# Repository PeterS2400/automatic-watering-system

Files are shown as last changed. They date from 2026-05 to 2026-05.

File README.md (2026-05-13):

# Automatic Plant Watering System

An automatic watering system for 8 potted plants. A single 12V solenoid valve releases water from a gravity-fed reservoir into a drip manifold. Each plant has its own Luer-slip syringe intermediate reservoir sized to hold exactly that plant's target water dose. When the valve opens all reservoirs fill simultaneously; when it closes, water drips slowly from each reservoir to its plant over 1–3 minutes. A Seeed Tiny BLE (nRF51822) controls the valve on a fixed 24-hour interval.

Per-plant water volume is controlled **physically** by syringe plunger position, not by software. The firmware only opens and closes the valve.

**Status:** Electronics assembled and firmware running. Valve cycle confirmed. Power path via barrel jack still being resolved. Enclosure CAD started.

---

## How it works

```
Gravity reservoir (2.5-gal HDPE bucket, ~1m above plants)
  [copper mesh basket inside, over bulkhead inlet]
  → 1/2" bulkhead → 1/2" ID silicone supply line
  → 12V solenoid valve (normally closed)
  → 1/2" ID silicone feed line
  → Orbit 67000 8-port drip manifold
  → 8× 1/4" ID fill lines → Luer-slip syringe intermediate reservoirs
  → 8× 1/8" ID silicone drip lines → plants
```

```
120V AC → Meanwell 12V/5A PSU → 12V rail
  → solenoid valve (via TIP121G NPN Darlington transistor switch)
  → LM2596 buck converter → 5V → Seeed Tiny BLE (USB injection)
```

---

## Architecture

Two approaches were evaluated before committing to hardware.

| | Option A — single valve (chosen) | Option B — per-plant valves |
|---|---|---|
| Valves | 1 | 8 |
| Electronics complexity | Low | Medium |
| Adjusting per-plant amounts | Slide syringe plunger | Change a config value |
| Plumbing complexity | Medium (intermediate reservoirs) | Low (direct drip lines) |

**Why Option A:** fewer failure points, simpler electronics, and volume adjustment doesn't require reflashing firmware. The intermediate reservoir approach is visible and debuggable — you can watch each reservoir fill and drain.

---

## Hardware

### Microcontroller

**Seeed Tiny BLE (nRF51822)** — ARM Cortex-M0, 16MHz, 3.3V logic.

- Timing: `millis()`-based 24-hour interval; no WiFi, no NTP, no RTC
- Drift: ~2–4s/day — acceptable for daily plant watering
- Programmed via CMSIS-DAP drag-and-drop: Sketch → Export Compiled Binary in Arduino IDE, drag `.hex` to the MBED drive in Finder. Board package: sandeepmistry nRF5, Generic nRF51.
- GPIO P4 drives the valve; nRF51822 requires H0H1 high-drive mode via direct NRF_GPIO register write (firmware handles this)
- LED pins (confirmed on hardware): GREEN = 21, RED = 22, BLUE = 23. Active LOW.

### Transistor driver

**TIP121G NPN Darlington** (TO-220), 470Ω base resistor, **10kΩ base pull-down to GND**, 1N4007 flyback diode.

- TIP121G is a Darlington with h_FE ≥ 1000 — nRF51822 H0H1 GPIO sources ~5mA, which saturates the TIP121G at 5A; the 500mA solenoid is trivial. The original ZTX650 was replaced because its h_FE of ~50–80 at 500mA was insufficient for saturation with 5mA base drive, causing it to operate in the linear region and overheat.
- Pinout (TO-220, leads facing you): B – C – E left to right; metal tab = collector
- 470Ω limits base current and accounts for the Darlington's two V_BE drops (~1.4V total): I_B = (3.3 − 1.4) / 470 ≈ 4mA
- **10kΩ pull-down** holds the base at 0V when the GPIO is inactive — a floating base picks up noise, partially enables the transistor, and generates destructive inductive spikes (this destroyed the first ZTX650 on initial power-up with the MCU disconnected)
- 1N4007 flyback diode clamps the inductive spike when the valve closes (cathode to 12V rail)
- No heatsink required — V_CE(sat) ≈ 1V at 500mA gives ~500mW dissipation, well within TO-220 limits

### Power

**Meanwell GST60A12** — 12V/5A desktop brick, UL/CE certified, continuous duty.

- 12V feeds solenoid coil (~500mA peak) and LM2596 input
- LM2596 buck converter steps down to 5V for Tiny BLE via USB injection; module uses screw terminals — Meanwell barrel jack connects via pigtail, no adapter needed

### Solenoid valve

12V DC, normally closed, 1/2" NPT, VITON seal (U.S. Solid brass body).

- **Direct-acting** — opens at zero pressure; works with gravity feed at any head height (pilot-operated valves require ~0.3 bar minimum pressure — avoid those)
- 1/2" NPT chosen over 1/4": the 1/2" valve has a ~10–12mm orifice so tubing, not the valve, is the flow bottleneck

### Intermediate reservoirs

All 8 plants use Luer-slip syringes with the plunger as an adjustable volume limiter.

- Fill tube (1/4" ID) drilled through center of plunger disc — interference fit + silicone sealant
- Plunger locked at desired volume mark with a cable tie through the barrel ears
- Drip line (1/8" ID) push-fits onto Luer nozzle — no barb fitting needed
- Volume adjustment: loosen cable tie, slide plunger to new mark, re-tighten

### Tubing

| Use | Spec |
|---|---|
| Supply runs (bulkhead → valve, valve → manifold) | 1/2" ID × 3/4" OD silicone, 10 ft |
| Fill lines (manifold → reservoirs) | 1/4" ID × 1/2" OD silicone, 25 ft |
| Drip lines (reservoirs → plants) | 1/8" ID × 1/4" OD silicone, 50 ft |

### Enclosure

3D-printed, two-part: body + lid. Lid secured with screws. Single parting line shared between the lid joint and both cable glands.

- **Power entry:** IEC C8 panel-mount socket; 12V DC pigtail from Meanwell barrel jack inside
- **Solenoid cable entry:** 2-wire, 12V switched; detachable connector inside (DIN 43650A preferred)
- **USB access:** remove lid — no panel port

Cable glands are fully integrated into the print. The body/lid split is the gland split — screwing the lid down clamps the cable. No purchased glands or separate clamp parts.

- Power cable bore: 5.9mm (cable OD 6.35mm)
- Solenoid cable bore: 2.8mm (cable OD 3.175mm)

Interior dimensions: 65mm × 85mm floor, 45mm height to parting line.

Boards mount via L-shaped corner extrusions from the walls. Bottom 2 corners are full L-shape (supports weight); top 2 corners are side tabs only (allows straight insertion from above, no overhangs to print). Boards sit slightly lower than their natural wire resting point so wire tension presses them into the supports.

---

## Firmware

**`firmware_ble/`** — Arduino C++ targeting Seeed Tiny BLE (nRF51822). Currently set to alternating open/closed cycle for calibration.

Key firmware constants (edit in `firmware_ble/watering_system/watering_system.ino`):

```cpp
#define VALVE_PIN    4   // GPIO pin to transistor base
#define VALVE_ON_S  20   // seconds valve stays open each cycle
#define VALVE_OFF_S 20   // seconds valve stays closed each cycle
```

LED: blue while valve is open, green while closed. 3 green blinks on boot.

---

## Bill of materials

### Electronics

| Item | Cost | Notes |
|---|---|---|
| Seeed Tiny BLE (nRF51822) | $0 (owned) | Microcontroller |
| 12V DC solenoid valve, NC, 1/2" NPT, VITON | $35 | U.S. Solid brass, direct-acting |
| TIP121G NPN Darlington transistor (TO-220) | $0 (stash) | Valve driver |
| 470Ω resistor (1/4W) | $0 (stash) | Base resistor |
| 10kΩ resistor (1/4W) | $0 (stash) | Base pull-down to GND |
| 1N4007 diode | $0 (stash) | Flyback protection |
| Meanwell GST60A12 12V/5A PSU | $0 (reused) | Continuous duty, UL/CE |
| LM2596 buck converter module (5-pack) | $9 | 12V→5V; screw terminal inputs |
| IEC C8 panel-mount socket | $0 (stash) | Power entry on enclosure |
| Perfboard, jumper wire, screw terminals | $0 (stash) | Driver circuit board |

### Plumbing

| Item | Cost | Notes |
|---|---|---|
| HDPE 2.5-gal black bucket + Gamma-seal lid | $18 | Food-grade, opaque |
| 1/2" NPT bulkhead fitting + EPDM gasket | — | Reservoir outlet (included in fittings total) |
| Copper mesh, 100–200 mesh, food-safe | $13 | Basket inside bucket over inlet |
| 1/2" NPT-F × 1/2" barb adapter, brass (×1) | — | Bulkhead → supply tube (included in fittings total) |
| 1/2" NPT-M × 1/2" barb adapter, brass (×3) | — | Valve inlet, valve outlet, manifold inlet (included in fittings total) |
| Bulkhead + barb adapters ×4 + PTFE tape | $25 | All fittings combined |
| Orbit 67000 8-port drip manifold | $18 | 1/2" FPT inlet, 1/4" barb outlets (bought 2-pack, 1 spare) |
| Silicone tubing 1/2" ID × 3/4" OD, 10 ft | — | Main supply runs (included in tubing total) |
| Silicone tubing 1/4" ID × 1/2" OD, 25 ft | — | Fill lines (included in tubing total) |
| Silicone tubing 1/8" ID × 1/4" OD, 50 ft | — | Drip lines (included in tubing total) |
| Silicone tubing (all 3 spools) | $35 | |

### Intermediate reservoirs

| Item | Cost | Notes |
|---|---|---|
| 150ml Luer-slip syringes (×6) | $23 | All plants; no small syringes needed |
| Cable zip ties (600pc) | $13 | Lock syringe plungers |
| Aquarium-grade silicone sealant | — | Included in sealant + pegboard total |
| Pegboard (syringe mounting, replaces rack) | — | Included in sealant + pegboard total |
| Silicone sealant + pegboard | $35 | |

### Enclosure

| Item | Cost | Notes |
|---|---|---|
| 3D-printed body + lid | $2 | Filament only; own printer |

### Cost summary

| Category | Cost |
|---|---|
| Electronics | $44 |
| Plumbing | $109 |
| Intermediate reservoirs | $71 |
| Enclosure | $2 |
| **Total** | **~$226** |

---

## Open items

- Resolve barrel-jack power path: LM2596 currently outputs 5V but Tiny BLE VCC pin expects 3.7–4.2V (LiPo range); either trim LM2596 to 4V or route 5V via USB injection permanently
- Update firmware from calibration cycle (20s on/off) to production schedule (24h interval) once fill duration is confirmed
- Determine per-plant water volumes → select small syringe sizes and quantities
- Calibrate valve open duration: increase VALVE_ON_S until all intermediate reservoirs fill without overflow
- Measure LM2596 module dimensions → model corner extrusions in CAD
- Finalize solenoid-side detachable connector (DIN 43650A preferred)
- Complete enclosure CAD and print
- Full system test

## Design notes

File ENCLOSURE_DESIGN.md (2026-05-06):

# Enclosure Design Notes

3D-printed enclosure, two-part: main body + lid. Lid secured with screws. Single parting line shared by lid joint and cable glands.

---

## External Interfaces

All penetrations through the enclosure wall.

### 1. Power Entry — 12V DC from Meanwell PSU

| Property | Detail |
|---|---|
| Signal | 12V DC, up to 5A |
| External connector | IEC 60320 C8 panel-mount socket (already decided) |
| Cable from Meanwell | Barrel jack (5.5×2.5mm, center+) → pigtail → C8 plug |
| Strain relief | Split cable gland, 3D-printed into enclosure body |
| Water resistance | Split gland geometry seals around cable jacket |
| Inside termination | Pigtail wires to perfboard screw terminals (12V+, GND) |

### 2. Solenoid Cable Entry — 12V switched + GND

| Property | Detail |
|---|---|
| Signal | 12V DC, ~500mA switched; 2-wire |
| Strain relief | Split cable gland, 3D-printed into enclosure body |
| Water resistance | Split gland geometry seals around cable jacket |
| Detachable connector | TBD — options discussed: DIN 43650A, GX12/GX16, XT30, pluggable screw terminal |
| Connector location | Inside the enclosure wall — cable gland on outside, connector socket on inside |
| Outside cable | Solenoid power cable, already attached to valve, terminates in mating connector plug |

### 3. USB Access — Tiny BLE programming

No panel interface. Remove lid to access USB port.

---

## Internal Components

| Component | Orientation | Mounting method |
|---|---|---|
| Seeed Tiny BLE (nRF51822) | Sideways (standing on edge) | 4 L-shaped corner extrusions from wall; lid presses top edge down to lock |
| LM2596 buck converter module | Sideways (standing on edge) | 4 L-shaped corner extrusions from wall; lid presses top edge down to lock |
| Perfboard | Flat | Standoffs from floor + M3 screws; drill holes in perfboard to match |

**Corner extrusion detail:**
- **Bottom 2 corners:** Full L-shape — captures the side and bottom edge of the board. Supports the board's weight and prevents forward/downward movement.
- **Top 2 corners:** Side tab only — grips the sides of the board but has no lip over the top edge. Prevents lateral movement without obstructing insertion from above. Avoids overhangs in the print.
- Lid closes over the top edge to provide the only top retention.
- Board drops straight in from above and lifts straight out — no angling or squeezing required.

Board dimensions (measured):
- Perfboard: 40mm × 60mm
- Seeed Tiny BLE: 38.5mm × 42mm
- LM2596 buck converter: TBD — measure before modeling

**Wire tension retention:** The Tiny BLE and LM2596 are positioned slightly lower than their natural resting point as determined by the connected wiring. The slight downward offset puts the wires in gentle tension/bend, which presses the boards down into their corner supports and prevents rattling without any additional fasteners.

Orient each board so tallest components face into available clearance.

---

## Dimensions

- Body interior height (floor to parting line): 45mm
- Body interior floor: 65mm × 85mm

## Lid

- Secured with screws (count and size TBD)
- Consider heat-set brass inserts in the body for cleaner screw attachment
- Lid removal provides USB access for firmware updates

---

## Split Cable Gland Design Notes

Both cable penetrations are fully integrated into the 3D-printed enclosure — no purchased glands, no separate clamp parts.

**Split geometry:**
- Single parting line: the body/lid split IS the gland split
- Lower half of each gland is part of the enclosure body; upper half is part of the lid
- Screwing the lid down clamps the cable — no additional hardware

**Bore and fit:**
- Power cable OD: 1/4" (6.35mm) → model bore at ~5.9mm
- Solenoid cable OD: 1/8" (3.175mm) → model bore at ~2.8mm
- Slight interference fit (~0.3–0.5mm under cable OD) so the lid clamps the jacket when tightened
- Interior shoulder or step inside the enclosure wall prevents the cable being pulled inward under tension

**Water resistance:**
- Exterior chamfer sheds water away from the opening
- Optionally apply a thin bead of silicone sealant inside the bore at final assembly for a positive seal

---

## Open Items

- Finalize solenoid-side detachable connector (DIN 43650A is the natural fit — same family as the connector on the valve coil itself)
- Decide USB access method (panel port vs. lid removal)
- ~~Measure actual cable ODs before modeling gland bores~~ **Resolved:** power 6.35mm, solenoid 3.175mm
- Determine screw size and count for lid
- Determine internal mounting strategy for perfboard and LM2596 module (standoffs, snap clips, or adhesive)

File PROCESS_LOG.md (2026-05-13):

# Process Log: Automatic Plant Watering System

---

## 2026-03-24 — Project initiation & BOM setup

### Decisions recorded

| Decision | Choice | Notes |
|---|---|---|
| Architecture | **Option A — single valve + intermediate reservoirs** | 1 solenoid valve; per-plant volume controlled by intermediate reservoir size |
| Plant count | **8 plants** | Upper end of planned range |
| Controller + driver | **ESP32 dev board + ZTX650 transistor circuit** | Single valve; same circuit as original CLAUDE.md design. 12V→5V buck converter for ESP32 power. |
| Intermediate reservoirs | **Hybrid: Luer-slip syringes (≤60ml) + PP lab bottles (>60ml)** | Syringes: plunger kept as adjustable fill ceiling; drill fill port through plunger disc; lock plunger with cable tie through barrel ears. Bottles: drill near base, rubber grommet + 1/8" barb; volume changed by swapping bottle size. |
| WiFi / remote control | **Yes — build it in now** | Schedule and status accessible remotely |
| Manifold | **Off-shelf 8-port drip manifold** | e.g. Orbit/Rain Bird; 1/4" barb outlets. Reducer couplers eliminated — fill lines are 1/4" ID silicone, direct fit on barb. |
| Enclosure | **3D-printed** | Custom design, no purchased project box |
| Power supply | **Meanwell GST60A12, 12V/5A desktop brick** | UL/CE certified, continuous duty; 5.5×2.5mm barrel jack |
| Fill line tubing | **Silicone, 1/4" ID × 1/2" OD, 25 ft spool** | Manifold → intermediate reservoir tops. Direct fit on 1/4" barb; fills 500ml in <10s at 1m head. |
| Drip line tubing | **Silicone, 1/8" ID × 1/4" OD, 50 ft spool** | Intermediate reservoir outlet → plant. Drains 200ml in ~1 min at 0.2m head. Target: 1–3 min delivery. |

---

### Tubing research — 2026-03-24

Compared four material options for the drip lines (gravity-fed, low-pressure, indoor).

**Materials evaluated:** silicone, vinyl/PVC, polyurethane (PU), PTFE

**Summary:**

| | Silicone | Vinyl (PVC) | PU | PTFE |
|---|---|---|---|---|
| Plant/food safe | Yes | Yes (food-grade only) | Yes (food-grade) | Yes |
| Flexibility | Excellent | Good | Good | Poor |
| Kink resistance | Moderate | Moderate | Good | Poor |
| Transparency | Clear grades available | Clear–hazy | Clear grades available | Milky/translucent |
| Barbed fitting fit | Excellent | Excellent | Good | Poor |
| Longevity | Excellent | Fair (hardens over years) | Good | Excellent |
| Cost | Moderate–high | Low | Moderate | Moderate–high |
| Indoor drip suitability | **Excellent** | Good | Good | Poor |

**Recommendation from research:** Silicone, 1/8" ID × 1/4" OD. Fully inert, stays flexible, fits barbed fittings without clamps, safe for plants long-term.

**Budget alternative (not selected):** Aquarium-grade vinyl airline tubing (3/16" ID) — adequate for indoor use, replace every 2–3 years.

**PTFE note:** Not suitable for flexible drip routing due to stiffness, but fine-bore PTFE capillary (~1/16" ID) could be used as a short in-line flow restrictor at the plant outlet if precise slow drip rates are needed.

**User selection:** Silicone (recommended option).

---

---

### Power supply research — 2026-03-24

Compared generic wall warts, reputable brand wall-mount, generic desktop bricks, and Meanwell branded bricks.

**Key findings:**
- System draws 8 × 500mA = 4A peak; ≥5A supply recommended for headroom
- Generic adapters: certification authenticity questionable; thermal performance at sustained 4A varies; not recommended for unattended 24/7 operation
- Meanwell: verified UL/CE, published MTBF (>100k hours), designed for continuous embedded deployment
- Barrel jack: generic adapters use 5.5×2.1mm; Meanwell typically uses 5.5×2.5mm — a $1 adapter resolves any mismatch
- Solenoids are inductive loads; switching PSUs handle them fine; flyback diodes already in BOM are the correct mitigation

**User selection:** Meanwell GST60A12 (12V/5A desktop brick).

---

### Reservoir research — 2026-03-24

Compared HDPE buckets, collapsible bladders, beverage dispensers, garden reservoirs, and jerrycans.

**Key findings:**
- Collapsible bladders: head pressure drops as they collapse — incompatible with gravity-fed flow
- Most beverage dispensers are clear/translucent — algae risk; opaque options hard to source reliably
- Jerrycans: excellent in all respects except no viable bottom outlet (shape prevents bulkhead fitting)
- HDPE bucket: opaque (black), food-grade, H₂O₂-compatible, easy bulkhead fitting, cheap, standard Gamma-seal lid available
- 2.5-gallon (9.5L) keeps full weight under 10kg on shelf; covers 2–3 watering cycles before refill

**User selection:** Black food-grade HDPE 2.5-gal bucket + Gamma-seal lid + 1/2" NPT bulkhead fitting + EPDM gasket.

---

### Fittings & manifold research — 2026-03-24

**Critical barb sizing clarification:** Barb OD matches tubing ID. 1/8" barb → 1/8" ID tubing. Standard drip manifolds use 1/4" barb outlets (sized for 1/4" ID poly tubing, not 1/8" ID silicone) — requires reducers.

**Manifold options evaluated:**
- Off-shelf (Orbit/Rain Bird 8-port): ~$10–20; outlets are 1/4" barb — needs 8× 1/4"→1/8" reducer couplers (~$4–16). Total ~$15–35.
- 3D-printed PETG with native 1/8" barbs: ~$7–12 in materials, no reducers, but requires design/print time. FDM is not inherently waterproof; PETG + CA glue coat seals adequately at gravity pressure.

**User selection:** Off-shelf manifold + 8× 1/4"→1/8" reducer couplers.

**Complete fitting chain:**
```
Reservoir bulkhead (1/2" NPT) → strainer → manifold (3/4" FHT or 1/2" NPT inlet)
→ manifold 1/4" barb outlets → 1/4"→1/8" reducer couplers × 8
→ 1/4" NPT close nipples × 8 → valve inlets (1/4" NPT-F)
→ valve outlets (1/4" NPT-F) → 1/4" NPT-M × 1/8" barb adapters × 8
→ 1/8" ID silicone drip lines × 8 → plants
```

**Sealing:** PTFE tape on all NPT threads; no hose clamps on silicone at gravity pressure.

---

### Valve driver research — 2026-03-24 (superseded by Option A switch)

Originally researched for Option B (8 valves). Superseded when architecture switched to Option A (1 valve). Full comparison retained in PROJECT_PLAN.md §1.6 for reference.

**Summary of what was found (for record):** ULN2803A (2 ICs, 4 channels each) was the lowest-cost DIY option; Waveshare ESP32-S3-ETH-8DI-8RO was the best all-in-one. Key ESP32 gotcha: 3.3V GPIO — most cheap relay modules require 5V and won't trigger reliably.

**Outcome:** Architecture switched to Option A (1 valve). Driver circuit reduced to single ZTX650 NPN transistor + 470Ω base resistor + 1N4007 flyback diode — the original CLAUDE.md design.

---

### Tubing flow rate research — 2026-03-24

Researched fill line and drip line sizing separately after deciding on two-tube approach.

**Fill lines (manifold → intermediate reservoirs):**
- Turbulent flow regime at relevant head heights — Darcy-Weisbach used
- 1/4" ID at 1m head fills 500ml in ~8s, 200ml in ~3s — essentially instantaneous
- 1/4" ID silicone fits directly on standard 1/4" barb manifold outlets → no reducer couplers needed
- **Selected: 1/4" ID × 1/2" OD silicone, 25 ft spool**

**Drip lines (intermediate reservoir → plant):**
- Laminar flow regime at ~0.2m head from small reservoirs
- 1/8" ID at 0.2m head, 1m run: ~200ml drains in ~40–60s; 50ml in ~10–15s
- PTFE capillary (0.8mm ID) evaluated — provides hours-long drip but rejected by user (target: 1–3 minute delivery)
- Length tuning viable for fine adjustment within ~2× range
- **Selected: 1/8" ID × 1/4" OD silicone, 50 ft spool**

---

### Intermediate reservoir research — 2026-03-24

Researched commercial products (syringes, IV bags, drip stakes) and DIY containers (bottles, Falcon tubes, 3D-printed, glass).

**Key findings:**
- Drip stakes and IV bags: not suitable (pressurized design / sealed fill problem)
- Falcon/centrifuge tubes: elegant conical drain, rack mounting included, but 50ml hard limit
- 3D-printed PETG: cleanest result with integrated barbs; needs design work and CA glue coat for waterproofing
- Oral syringes (Luer-slip, plunger removed): zero modification, 1/8" silicone push-fits directly onto Luer nozzle, 10–60ml range
- PP lab reagent bottles (wide-mouth): drill near base, rubber grommet + 1/8" barb, 125–500ml range. Do NOT use hot glue (fails on PP). Silicone sealant alone won't bond PP without primer — rubber grommet is primary seal.

**User selection:** Hybrid — syringes for small plants (≤60ml), PP lab bottles for large plants (>60ml).

- [x] Architecture switched to **Option A** — 1 valve, intermediate reservoirs. Electronics simplified to ESP32 + single ZTX650 circuit.
- [x] Intermediate reservoir type selected: **syringes (≤60ml) + PP lab bottles (>60ml)**
- [x] Syringe volume control: **plunger-as-limiter** — drill fill port through plunger disc, lock plunger position with cable tie through barrel ears. Continuously adjustable, readable from barrel graduation markings.
- [x] Tubing: two sizes — 1/4" ID fill lines (fast), 1/8" ID drip lines (1–3 min delivery)
- [x] Reducer couplers eliminated — 1/4" ID fill lines fit directly on manifold 1/4" barb outlets
- [ ] Determine per-plant water volumes → confirm syringe/bottle sizes and quantities needed

---

### Open items as of 2026-03-24

- [x] Silicone tubing: **1/4" ID × 1/2" OD, 25 ft** (fill lines) + **1/8" ID × 1/4" OD, 50 ft** (drip lines)
- [x] Reducer couplers eliminated — fill lines are 1/4" ID, direct fit on manifold barbs
- [ ] Determine per-plant water volumes → finalize syringe/bottle sizes and quantities
- [ ] Barrel jack adapter (5.5×2.5mm → 5.5×2.1mm) — confirm during electronics design
- [ ] Manifold specific product — confirm outlet type (1/4" NPT-F vs. 1/4" barb) before ordering fittings

---

## 2026-03-24 — Manifold selection, BOM refinements, electrical interface documentation

### Intermediate reservoir quantities confirmed

Minimum quantities set: **at least 4 syringes** (≤60ml plants) + **at least 4 bottles** (>60ml plants). Final sizes still TBD per plant. BOM updated from TBD to 4+.

---

### Manifold research — 2026-03-24

Researched 6 manifold types: off-shelf drip irrigation, aquarium/hydroponics, DIY barbed tee chain, DIY 1/2" header with punch-ins, drilled PVC pipe, 3D-printed PETG. Full detail in `manifold_options.md`.

**Key findings:**

| Finding | Result |
|---|---|
| Off-shelf 8-port manifold outlet type | **1/4" barb universally** (Orbit, Raindrip, Rain Bird, DIG) — not NPT-F. Direct fit for 1/4" ID silicone fill lines. |
| Off-shelf manifold inlet type | **1/2" FPT** on all models — needs one adapter to connect to 1/4" ID supply line |
| Gravity-feed compatibility | Non-pressure-compensating manifolds pass gravity flow freely with knobs open. Pressure-compensating emitter inserts block flow at gravity pressure — do not install. |
| Aquarium manifolds | Outlet barbs are 3/16" or ~5.5mm — too small for 1/4" ID fill lines. Not compatible. |

**User selection:** **Orbit 67000** (~$8) + **Rain Bird XT025** inlet adapter (1/4" barb × 1/2" FPT female, ~$1–2).

**Resolved open item:** Manifold outlet type confirmed as 1/4" barb. No NPT-F adapters needed at outlet side.

---

### LM2596 datasheet review — 2026-03-24

Reviewed Addicore AD281 LM2596 datasheet. Document is the National Semiconductor LM2596 IC datasheet — covers the 5-pin TO-220/TO-263 chip only. No barrel jack is present on the IC itself.

**Finding:** The LM2596 module board (Addicore AD281 and equivalent cheap modules) uses **screw terminals** for 12V input and 5V output — no barrel jack socket. The Meanwell PSU's 5.5×2.5mm barrel jack therefore does not plug into a module socket; instead the 12V is distributed via a pigtail wire from the barrel jack to screw terminals on the perfboard.

**Resolved open item:** Barrel jack adapter (5.5×2.5mm → 5.5×2.1mm) — **not applicable**. No adapter needed.

---

### Inline strainer replaced with copper mesh basket — 2026-04-22

**Decision:** Remove inline sediment strainer; use copper mesh basket inside the bucket instead.

**Rationale:** A copper mesh basket (100–200 mesh) formed over the bulkhead inlet opening inside the bucket does the same filtration job as an inline strainer while also providing the antimicrobial Cu²⁺ release already planned for water quality. Consolidates two separate items into one, removes a plumbing fitting from the line, and simplifies the supply chain.

**Changes made:**
- Inline strainer row removed from BOM
- Copper mesh sheet/roll added to BOM (replaces both strainer and previously separate copper insert)
- Fitting chain updated: bulkhead → valve directly (strainer hop removed)
- Section 1.3 water quality note updated to describe dual-purpose copper mesh basket

---

### Bucket-to-valve tube segment added — 2026-04-22

**Issue:** Removing the inline strainer left the fitting chain with no tubing or adapters specified between the bulkhead and the valve inlet. That segment was silently missing from the BOM.

**Changes made:**
- Added 1/2" NPT-F × 1/2" barb adapter (×1) — female NPT threads onto bulkhead's external male NPT thread; barb accepts supply tube
- 1/2" NPT-M × 1/2" barb adapter qty increased from 2 to 3 (valve inlet added to existing valve outlet + manifold inlet uses)
- 1/2" ID silicone spool bumped from 5 ft to 10 ft to cover both runs (bulkhead→valve and valve→manifold)
- Fitting chain, BOM, system diagram, and CLAUDE.md all updated

---

### Main feed line upsized to 1/2" ID — 2026-04-22

**Decision:** Use 1/2" ID tubing for the entire main supply run — from reservoir bulkhead through the valve to the manifold inlet.

**Rationale:** The manifold inlet is 1/2" FPT. Dropping to 1/4" ID between the valve outlet and the manifold inlet was an unnecessary restriction. Keeping full 1/2" bore throughout the supply path eliminates all restrictions above the manifold; the 1/4" barb outlets on the manifold itself are where the flow splits and naturally reduces.

**Changes made:**
- Main feed line: 1/4" ID × 1/2" OD → **1/2" ID × 3/4" OD** silicone, short spool (5 ft added to BOM)
- Valve outlet adapter: 1/2" NPT-M × 1/4" barb → **1/2" NPT-M × 1/2" barb** (qty 2 — one at valve outlet, one at manifold inlet)
- Rain Bird XT025 inlet adapter (1/4" barb × 1/2" FPT) removed — no longer needed
- Fitting chain and CLAUDE.md updated throughout

---

### Solenoid valve upsized to 1/2" NPT — 2026-04-22

**Decision:** Switch solenoid valve from 1/4" NPT to 1/2" NPT.

**Rationale:** A 1/4" NPT direct-acting solenoid valve has an internal orifice of ~3–4mm, which is smaller than the 6.35mm bore of the 1/4" ID fill tubing and far smaller than the 1/2" NPT upstream plumbing (bulkhead, strainer). The valve orifice was the system's primary flow restriction. A 1/2" NPT valve has a ~10–12mm orifice — the 1/4" ID tubing becomes the bottleneck, which is the correct behavior for a gravity-fed system trying to fill reservoirs quickly.

**Changes made:**
- Valve spec: 1/4" NPT → 1/2" NPT throughout CLAUDE.md and PROJECT_PLAN.md
- Valve outlet adapter: 1/4" NPT-M × 1/4" barb → 1/2" NPT-M × 1/4" barb (connects valve outlet to 1/4" ID main feed line)
- Fitting chain updated (bulkhead → strainer → valve inlet/outlet all remain 1/2" NPT; reduction to 1/4" barb happens at valve outlet adapter)

---

### Electrical interfaces documented — 2026-03-24

Added a full electrical interface table to PROJECT_PLAN.md covering every connection in the system:

| Interface | Connection type |
|---|---|
| Wall → Meanwell | IEC C14 / country plug, 120V AC |
| Meanwell → 12V rail | 5.5×2.5mm barrel jack → pigtail wire → perfboard screw terminal |
| 12V rail → solenoid (+) | Wire → DIN 43650A connector |
| 12V rail → LM2596 IN+ | Wire → screw terminal |
| LM2596 OUT+ → ESP32 5V | Wire → ESP32 5V/VIN pin |
| ESP32 GPIO → transistor base | Wire on perfboard → 470Ω → ZTX650/651 base |
| Transistor collector → solenoid (−) | Wire → DIN 43650A connector |
| Flyback diode | 1N4007 across solenoid coil, cathode to 12V |
| Common GND | Single ground bus: Meanwell GND sleeve, LM2596 IN−/OUT−, ESP32 GND, transistor emitter |

---

## 2026-04-28 — Hardware procurement begun

### Items ordered

| Item | Qty | Notes |
|---|---|---|
| LM2596 buck converter module (5-pack) | 5 | 1 used; 4 spares |
| 150ml Luer-slip syringes (3-pack) | 3 | For higher-volume plants |
| Copper mesh woven filter, 3m roll | 1 | Basket filter inside main reservoir over bulkhead inlet |
| Nylon zip ties, assorted sizes (600pc) | 1 pack | Syringe plunger locking + general cable management |
| DIN 43650A solenoid connector plug w/ LED | 1 | LED provides visual confirmation when valve is energized |
| Orbit 67000 8-port drip manifold (2-pack) | 2 | 1 used; 1 spare |

### Design decisions confirmed — 2026-04-28

- **All intermediate reservoirs are syringes.** PP lab bottles removed from design. 150ml Luer-slip syringes replace the PP bottle approach for higher-volume plants. All 8 plants use the same plunger-as-volume-limiter construction — no grommet drilling or sealant needed. PP bottles, grommet fittings, and silicone sealant removed from BOM.
- **Second Orbit 67000 is a spare.** BOM qty remains 1.
- **150ml syringe quantity updated to 6** (second 3-pack ordered). BOM updated accordingly.
- **DIN 43650 connector removed from BOM** — valve ships with connector included.
- **Syringe fill-port construction method confirmed:** 1/4" ID fill tube passes directly through a drilled hole in the plunger disc (no barb fitting); silicone sealant seals around the tube. Luer nozzle tip accepts 1/8" ID drip line by push-fit. 1/4" barb fittings (×8) removed from BOM; aquarium-grade silicone sealant added back.
- **`intermediate_reservoir_options.md` removed.** File contained research on 5 container types (small plastic bottles, Falcon/culture tubes, 3D-printed PETG, glass jars, repurposed food containers) and 4 outlet sealing methods (rubber grommet, threaded bulkhead, aquarium silicone, hot glue). Design is now settled on Luer-slip syringes for all 8 reservoirs, making the container research moot. Full content available in git history if needed.

---

## 2026-05-06 — Microcontroller switch; firmware rewrite; electronics assembly begun

### Microcontroller switched to Seeed Tiny BLE (nRF51822)

**Decision:** Replace ESP32 with Seeed Tiny BLE for the active build.

**Rationale:** Board was already on hand. Using it avoids waiting on ESP32 procurement and allows hardware assembly to begin immediately.

**Implications:**
- No WiFi, no NTP. Timing is millis()-based 24h interval. Drift ~2–4s/day — acceptable for daily plant watering.
- Schedule changes require re-uploading firmware via USB/SWD drag-and-drop.
- nRF51822 GPIO standard drive (~0.5mA) is insufficient to saturate ZTX650/651 at 500mA collector current through a 470Ω base resistor. H0H1 high-drive mode must be set via direct NRF_GPIO register write after `pinMode()` — firmware handles this.
- Upload method: compile in Arduino IDE (sandeepmistry/arduino-nRF5 board package, Nordic nRF51X22 Development Kit), then `cp watering_system.ino.bin /Volumes/MBED/` via Terminal. macOS Finder drag-and-drop fails silently.

**ESP32 / MicroPython path:** Preserved in `firmware/`, deferred until ESP32 is acquired.

---

### Firmware rewritten in Arduino C++ for Tiny BLE

`firmware_ble/watering_system/watering_system.ino` is the active firmware.

Key implementation decisions:
- `VALVE_PIN 4` (P4 on Tiny BLE header)
- `FILL_DURATION_S 2` — start low, calibrate upward until reservoirs fill without overflow
- `VALVE_MAX_ON_S 60` — hard safety cap regardless of config
- Valve pin written LOW before `pinMode(OUTPUT)` to guarantee closed state from first clock cycle
- UL suffixes on interval constant (`24UL * 60UL * 60UL * 1000UL`) prevent 32-bit overflow before type widening
- Unsigned subtraction for millis() rollover safety
- Waters immediately on first boot for circuit verification; then every 24h
- LED status: 3× green blink on boot, solid green while running, blue during valve open

---

### Transistor failure on first power-up; pull-down resistor added

**Incident:** ZTX650 destroyed on first power-up. Microcontroller was unplugged (intentionally, to protect it). Valve energized briefly, then transistor failed.

**Root cause:** With the microcontroller disconnected, the base pin was floating through the 470Ω resistor to nothing. A floating base picks up noise and capacitive coupling from nearby conductors, drifting above the ~0.6V threshold and partially or fully enabling the transistor. The solenoid coil, being an inductor, generated inductive spikes each time the transistor switched erratically. Repeated spikes with the transistor in a partially-on (high-resistance) state exceeded the junction's power dissipation; transistor failed collector-to-emitter short.

**Fix:** Added 10kΩ pull-down resistor from base to GND. Holds base firmly at 0V when GPIO is not actively driving it. Prevents partial conduction, erratic switching, and resulting spike damage. BOM and assembly docs updated.

**Solenoid:** Not damaged. Coil survived — it released energy into the spike but did not absorb a damaging voltage itself.

**Flyback diode orientation confirmed correct:** cathode (silver stripe) to 12V rail.

**Pull-down resistor color code:** Brown-Black-Orange-Gold (10kΩ, 5% tolerance). A 5th yellow band indicates military-grade reliability rating — value is still 10kΩ.

---

### Enclosure design completed

3D-printed two-part enclosure (body + lid) designed. Full detail in `ENCLOSURE_DESIGN.md`.

**Key decisions:**
- Single parting line serves as both the lid joint and the cable gland split — no separate gland hardware
- Power entry: IEC C8 panel-mount socket; 12V DC via Meanwell barrel jack pigtail inside
- Solenoid cable entry: 2-wire split gland; DIN 43650A detachable connector inside (preferred — matches connector family already on valve coil)
- USB access: remove lid; no panel port
- Cable gland bores: power 5.9mm (cable OD 6.35mm), solenoid 2.8mm (cable OD 3.175mm)
- Interior dimensions: 65mm × 85mm floor, 45mm height to parting line
- Board mounting: L-shaped corner extrusions from walls; bottom 2 corners full L-shape (supports weight), top 2 corners side tab only (allows straight insertion, avoids overhangs in print)
- Wire tension retention: boards sit slightly lower than natural wire resting point so wires press boards into supports — no extra fasteners

**Dimensions confirmed:**
- Perfboard: 40mm × 60mm (measured)
- Seeed Tiny BLE: 38.5mm × 42mm (measured)
- LM2596 module: TBD — measure before modeling corner extrusions

---

## 2026-05-13 — Firmware running; total project cost tallied

### Firmware confirmed working

Firmware flashed to Tiny BLE via MBED drag-and-drop (sandeepmistry nRF5 package, Generic nRF51 board). Valve alternating open/closed on 20s cycle confirmed. LED corrected: GREEN = pin 21, RED = pin 22 (initial assignment was swapped).

**Power path note:** Barrel jack → LM2596 → board is unresolved. LM2596 outputs 5V but Tiny BLE VCC pin expects 3.7–4.2V. Board currently powered via USB during development.

**Small syringes:** Not needed — all 8 plants will use 150ml syringes.

---

### Total project cost

All prices confirmed against actual purchases. Ranges use midpoints.

| Item | Cost |
|---|---|
| 12V solenoid valve (U.S. Solid, 1/2" NPT) | $35 |
| LM2596 buck converter 5-pack | $9 |
| HDPE bucket + Gamma-seal lid | $18 |
| Bulkhead fitting, barb adapters ×4, PTFE tape | $25 |
| Copper mesh roll (3m) | $13 |
| Orbit 67000 manifold (2-pack, 1 used) | $18 |
| Silicone tubing — 1/2", 1/4", 1/8" spools | $35 |
| 150ml Luer-slip syringes ×6 | $23 |
| Zip ties (600pc) | $13 |
| Silicone sealant + pegboard | $35 |
| Enclosure filament | $2 |
| Meanwell PSU, Seeed Tiny BLE, all electronics | $0 (reused / from stash) |
| **Total** | **~$226** |

Items at $0: Meanwell GST60A12 (reused), Seeed Tiny BLE (already owned), TIP121G, resistors, 1N4007, IEC C8 socket, perfboard, jumper wire, screw terminals (all from existing parts stash).

---

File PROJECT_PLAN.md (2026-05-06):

# Project Plan: Automatic Plant Watering System

---

## Architecture Decision: Single Valve vs. Per-Plant Valves

Two viable approaches. Choose one before proceeding with hardware procurement.

### Option A — Single Valve + Intermediate Reservoirs
- One solenoid valve on the main line; valve opens to fill all intermediate reservoirs simultaneously
- Per-plant volume controlled **physically** by reservoir size
- Simpler electronics (1 transistor circuit)
- Adjusting water amounts requires physical modification (swap/resize a reservoir)
- No firmware changes needed to change per-plant amounts

### Option B — Per-Plant Valves
- One solenoid valve per plant (5–8 valves), all fed from a common manifold
- Per-plant volume controlled **by software** (each valve open for a different duration)
- More complex electronics (1 transistor circuit per valve, or a relay/MOSFET board)
- Adjusting water amounts is a config/firmware change only — no plumbing changes
- Enables watering plants at different times or skipping individual plants
- Higher component cost; Arduino Uno has enough digital GPIO pins for 5–8 outputs

**Tradeoffs summary:**

| | Option A | Option B |
|---|---|---|
| Valves | 1 | 5–8 |
| Electronics complexity | Low | Medium |
| Adjusting amounts | Physical (swap reservoir) | Software (change duration) |
| Plumbing complexity | Medium (intermediate reservoirs) | Low (direct drip lines) |
| Firmware complexity | Low | Low–Medium |

---

## Bill of Materials

> **Architecture selected: Option A — single valve + intermediate reservoirs, 8 plants, Seeed Tiny BLE (nRF51822).**
> Intermediate reservoirs: Luer-slip syringes for all 8 plants — smaller syringes (≤60ml) for lower-volume plants, 150ml syringes for higher-volume plants. Final sizes TBD per plant.

### Electronics

| Qty | Item | Notes |
|---|---|---|
| 1 | 12V DC Solenoid Valve, NC, 1/2" NPT, VITON seal | U.S. Solid brass — direct-acting, gravity-compatible. Option A uses 1 valve only. |
| 1 | Seeed Tiny BLE (nRF51822) | ARM Cortex-M0, 3.3V logic. Interval-based 24h timing via millis(). No WiFi, no NTP. |
| 1 | ZTX650 or ZTX651 NPN transistor | Single valve driver |
| 1 | 470Ω resistor (1/4W) | Base resistor for transistor |
| 1 | 10kΩ resistor (1/4W) | Pull-down from transistor base to GND — prevents floating base from partially enabling transistor when GPIO is inactive |
| 1 | 1N4007 diode (flyback) | Across solenoid coil — cathode to 12V, anode to GND |
| 1 | Meanwell GST60A12 12V/5A desktop brick power supply | UL/CE certified, continuous duty. Output: 5.5mm × 2.5mm barrel jack (center positive). 12V rail feeds solenoid coil and LM2596 module input. |
| 5 | **LM2596 DC to DC Buck Converter 3.0-40V to 1.5-35V Power Supply Step Down Module** (5-pack) | Input and output via **screw terminals** — no barrel jack. 12V IN+/IN− screws to Meanwell rail; 5V OUT+/OUT− screws to Tiny BLE USB injection. 1 used; 4 spares. |
| 1 | IEC C8 panel-mount socket | Power entry on enclosure; mates with C8 plug on Meanwell barrel jack pigtail |
| — | Perfboard, jumper wires, screw terminals | For transistor driver circuit board |

**Timekeeping:** millis()-based 24h interval. No RTC, no NTP, no WiFi required. Drift ~2–4s/day — acceptable for daily plant watering.

### Electrical Interfaces

All connections between major components. No barrel jack adapter required — the Meanwell output barrel jack is not plugged into any module socket; 12V is distributed from the barrel jack via a pigtail cable to screw terminals on the perfboard.

| Interface | From | To | Connection type | Signal / voltage |
|---|---|---|---|---|
| AC mains → PSU | Wall outlet | Meanwell GST60A12 | IEC C14 / country plug | 120V AC |
| PSU → 12V rail | Meanwell barrel jack (5.5×2.5mm, center+) | Perfboard power bus (pigtail wire to screw terminal) | Barrel jack → pigtail → screw terminal | 12V DC, up to 5A |
| 12V rail → solenoid | Perfboard 12V bus | Solenoid coil (+), via DIN 43650A connector | Wire | 12V DC, ~500mA when on |
| 12V rail → LM2596 IN | Perfboard 12V bus | LM2596 module IN+ screw terminal | Wire to screw terminal | 12V DC |
| LM2596 GND | Perfboard GND bus | LM2596 module IN− screw terminal | Wire to screw terminal | GND (common) |
| LM2596 OUT → ESP32 | LM2596 module OUT+ screw terminal | ESP32 5V pin (or VIN) | Wire | 5V DC, ≤1A |
| LM2596 OUT GND → ESP32 | LM2596 module OUT− screw terminal | ESP32 GND pin | Wire | GND (common) |
| LM2596 OUT → Tiny BLE | LM2596 module OUT+ screw terminal | Tiny BLE USB 5V injection | Wire | 5V DC, ≤1A |
| LM2596 OUT GND → Tiny BLE | LM2596 module OUT− screw terminal | Tiny BLE GND | Wire | GND (common) |
| Tiny BLE GPIO → transistor | Tiny BLE P4 (3.3V logic, H0H1 high-drive mode) | ZTX650/651 base via 470Ω resistor | Wire on perfboard | 3.3V logic, ~7mA base current |
| Base pull-down | ZTX650/651 base | GND | 10kΩ resistor | Holds base at 0V when GPIO inactive |
| Transistor → solenoid (−) | ZTX650/651 collector | Solenoid coil (−), via DIN 43650A connector | Wire | Switched 12V return path, ~500mA |
| Flyback diode | Solenoid coil (−) / collector node | Solenoid coil (+) / 12V rail | 1N4007 across coil | Clamps inductive spike to ~12.7V |
| Common GND | Meanwell GND (barrel jack sleeve) | Perfboard GND bus → LM2596 IN− → Tiny BLE GND → transistor emitter | Wire | All grounds tied together |

### Plumbing

#### Main Reservoir & Valve

| Qty | Item | Notes |
|---|---|---|
| 1 | Black food-grade HDPE bucket, 2.5-gallon (9.5L) | Opaque; blocks light to prevent algae |
| 1 | Gamma-seal lid (fits 2.5-gal bucket) | Dust-tight, insect-proof, easy refilling |
| 1 | 1/2" NPT bulkhead fitting, HDPE or nylon, EPDM gasket | Drilled into side wall near bottom. Avoid natural rubber (H₂O₂ incompatible) |
| 1 | **3-Meter Copper Mesh Woven Filter Column Packing, 4-wire, sanitary/food-grade** | Cut and form into a cup/basket inside bucket over the bulkhead inlet opening. Filters sediment and provides slow Cu²⁺ antimicrobial release — replaces both inline strainer and separate copper insert. |
| 1 | 1/2" NPT-F × 1/2" barb adapter, brass | Bulkhead external thread (1/2" NPT-M) → 1/2" ID supply tube to valve. Female NPT onto bulkhead, barb accepts hose. |
| 3 | 1/2" NPT-M × 1/2" barb adapter, brass | One at valve inlet (1/2" NPT-F) ← supply tube from bulkhead; one at valve outlet → main feed line; one at manifold inlet ← main feed line. Same part all three. |
| 1 | PTFE tape, 1/2" roll | Seal all NPT male threads; 2–3 wraps |

#### Distribution Manifold

| Qty | Item | Notes |
|---|---|---|
| 1 | **Orbit 67000 8-Port Adj Flow Drip Manifold** | 1/2" FPT inlet, eight 1/4" barb outlets — direct fit for 1/4" ID silicone fill lines. Individual rotary flow controls (open fully for gravity feed). Built-in filter screen. Non-pressure-compensating — no minimum pressure required. |

#### Intermediate Reservoirs (per-plant volume control)

One reservoir per plant, sized to hold that plant's exact target water dose. Valve opens → all reservoirs fill simultaneously → valve closes → water drips slowly from each reservoir to its plant.

**All plants — Luer-slip syringes with plunger volume limiter, sized per plant:**

| Qty | Item | Notes |
|---|---|---|
| 4+ | Oral syringe, Luer-slip, with plunger, 10–60ml | For lower-volume plants. e.g. Norm-Ject all-PP syringes. ~$0.20–1.50 each. Source: pharmacy or Amazon ("oral syringe no needle Luer slip") |
| 6 | **150ml Large Syringes for Liquid, Oral, Scientific Labs, Measurement, Dispensing, with Cap** | For higher-volume plants. Plunger-as-volume-limiter approach (same as small syringes). Luer nozzle is the drip outlet — no drilling required. |
| 1 pack | **Cable Zip Ties, 600pc Self-Locking Nylon, Assorted 4/6/8/10/12-inch** | One per syringe. Thread through barrel ears (thumb ring) to lock plunger at desired volume mark. Slide plunger to adjust, re-tie to lock. |
| 1 | Aquarium-grade silicone sealant (e.g. GE Silicone I, 100% silicone, no mildewcide) | Seal around 1/4" ID fill tube where it passes through the drilled plunger hole. Drill hole slightly undersized (~7/16") for interference fit — tube friction is the primary seal; silicone fills the gap. 24h before water contact, 7-day full cure. |
| 1 | Syringe holder rack or clip | Mount syringes vertically above plants; lab-style 6–8 position racks ~$5–15 on Amazon |

**Syringe construction:** Drill ~7/16" hole through center of plunger disc; force 1/4" ID × 1/2" OD fill tube through (interference fit seals by friction); apply silicone around tube at plunger face; cure before use. Luer nozzle at tip accepts 1/8" ID drip line by push-fit — no barb or sealant needed.

**Volume adjustment procedure:** Loosen cable tie → slide plunger to desired volume mark on barrel → re-tighten cable tie. Volume = space between plunger face and Luer nozzle tip. Readable directly from barrel graduation markings.

#### Tubing

Two distinct sizes — fill lines are wider (fast fill from manifold), drip lines are narrower (controlled 1–3 minute delivery to plant).

| Qty | Item | Notes |
|---|---|---|
| 1 spool (10 ft) | Silicone tubing, food-grade, **1/2" ID × 3/4" OD** | Two runs: bulkhead → valve inlet, and valve outlet → manifold inlet. 10 ft covers both segments with margin regardless of layout. |
| 1 spool (25 ft) | Silicone tubing, food-grade, **1/4" ID × 1/2" OD** | Fill lines: manifold 1/4" barb outlets → intermediate reservoir tops. Direct fit on barbs — no reducers. Fills even a 500ml reservoir in <10 seconds at 1m head. |
| 1 spool (50 ft) | Silicone tubing, food-grade, **1/8" ID × 1/4" OD** | Drip lines: intermediate reservoir outlet → plant. At ~0.2m head from a syringe/bottle, 200ml drains in ~1 minute. 8 runs × ≤3 ft = 24 ft max; 50 ft spool gives margin. |

**Drip line timing:** At 0.2m head (typical syringe or bottle height), 1/8" ID drains ~200ml in ~40–60 seconds. Smaller reservoirs (50ml) deliver in ~10–15 seconds. Adjust reservoir size to control volume; tube length can fine-tune rate within ~2× range if needed.

#### Fitting Chain

```
Gravity reservoir (HDPE bucket)
  → bulkhead fitting (1/2" NPT)  [copper mesh basket inside bucket over inlet]
  → [1/2" NPT-F × 1/2" barb adapter] → 1/2" ID supply tube → [1/2" NPT-M × 1/2" barb adapter]
  → solenoid valve inlet (1/2" NPT-F)
  → valve outlet (1/2" NPT-F) → [1/2" NPT-M × 1/2" barb adapter]
  → 1/2" ID main feed line
  → [1/2" NPT-M × 1/2" barb adapter] → 8-port distribution manifold (1/2" FPT inlet, Orbit 67000)
  → [1/4" barb outlets] × 8 → 1/4" ID silicone fill lines (direct fit, no reducers)
  → drop into tops of intermediate reservoirs
  → [syringe Luer nozzle] × 8
  → 8× 1/8" ID silicone drip lines
  → plants
```

**Sealing notes:** PTFE tape on all NPT threads (2–3 wraps). No hose clamps on silicone at gravity pressure. GHT connections seal with EPDM washer only.

### Tubing Research Summary

See PROCESS_LOG.md for full comparison. Four options evaluated: silicone, vinyl/PVC, polyurethane, PTFE.

**Selected: silicone, 1/8" ID × 1/4" OD.**

- Fully plant-safe and inert; no plasticizer concerns
- Stays flexible at room temperature; easy to route around pots
- Fits standard 1/8" barbed fittings without clamps under gravity pressure
- Does not harden or crack over multi-year service life
- Clear grades allow visual flow confirmation
- Moderate kink resistance — use gentle curves, not tight bends
- Cost is moderate–high; small premium justified for permanent indoor installation

**Alternative not selected:** Aquarium-grade vinyl airline tubing (3/16" ID) — proven, cheap, adequate for short-term use; hardens over 2–3 years.

**PTFE note:** Not suitable for flexible runs, but fine-bore PTFE capillary (1/16" ID, 5–15cm segment) can serve as an in-line flow restrictor at the plant outlet if drip rate needs to be reduced.

### Enclosure

| Qty | Item | Notes |
|---|---|---|
| — | 3D-printed enclosure | Custom design; no purchased box |

---

## Phase 1 — Hardware Design & Procurement

### 1.1 Solenoid Valve
- **Selected:** U.S. Solid 1/2" Brass Solenoid Valve, 12V DC, Normally Closed, VITON seal
- VITON seal is chemically resistant — compatible with H₂O₂ water treatment
- 1/2" NPT fittings — matches upstream bulkhead and strainer; no restriction relative to 1/4" ID fill lines
- Normally closed = safe default (valve stays closed if power is lost)
- **Direct-acting** (confirmed) — opens at zero pressure, fully compatible with gravity-fed reservoir at any height
- **Why 1/2" over 1/4":** A 1/4" NPT direct-acting valve has a ~3–4mm internal orifice, which is the system bottleneck and restricts flow below what the 1/4" ID tubing can carry. A 1/2" NPT valve has a ~10–12mm orifice; the tubing becomes the limiting factor, not the valve.
- **Option A:** purchase 1 valve; **Option B:** purchase 1 per plant (5–8)

### 1.2 Per-Plant Water Delivery

**Option A — Intermediate Reservoirs**
- Determine required water volume per plant
- Select or fabricate small containers (e.g. syringes, small bottles, 3D-printed cups)
- Size each reservoir to hold exactly the desired per-plant volume
- Drill/fit outlet for drip tube at the bottom
- Choose drip tube diameters so reservoirs empty slowly but fully before the next cycle

**Option B — Direct Drip Lines**
- Run one tube directly from manifold to each plant
- No intermediate reservoirs needed
- Per-plant volume set by valve open duration in firmware

### 1.3 Main Reservoir — Water Quality
- Use an **opaque container** to block light and prevent algae growth
- **Seal or cover the top** to keep out dust, insects, and airborne spores
- Place reservoir in a **cool, shaded spot** — warm water accelerates bacterial growth
- Place a **copper mesh basket** (100–200 mesh) inside the bucket over the bulkhead inlet opening; serves dual purpose: filters sediment before it enters the line, and provides slow Cu²⁺ release which is naturally antimicrobial and safe for plants at trace levels. No separate inline strainer needed.
- Periodically add a small dose of **food-grade hydrogen peroxide** (~1–3ml of 3% H₂O₂ per liter) to kill bacteria and algae; breaks down into water and oxygen, safe for plants
- **Flush and refill** every 1–2 weeks to prevent stagnation; plan a refill reminder into the schedule

### 1.4 Manifold & Plumbing
- Main gravity reservoir → valve inlet (Option A: single valve; Option B: valve → manifold → per-plant valves)
- Valve outlet → manifold (T-fittings or drilled bar)
- **Option A:** manifold → intermediate reservoirs → thin drip tubes to plants
- **Option B:** manifold → one direct drip line per plant

### 1.5 Electronics BOM

**Current build (Option A, Seeed Tiny BLE):**
- Seeed Tiny BLE (nRF51822) — already owned
- ZTX650 or ZTX651 NPN transistor (single valve driver)
- 470Ω resistor (base resistor)
- 10kΩ resistor (base pull-down to GND)
- 1N4007 flyback diode
- Meanwell GST60A12 12V/5A PSU
- LM2596 buck converter module (12V→5V, screw terminals)
- IEC C8 panel-mount socket
- Perfboard, jumper wires, screw terminals

**If expanding to Option B (future, requires ESP32):**
- 1× ZTX650/651 NPN transistor per plant (8 total), or 2× ULN2803A Darlington ICs
- See Section 1.6 for full 8-channel driver comparison

> **Valve driver selection research:** See Section 1.6 below for a full comparison of all reasonable options for driving 8× 12V/500mA solenoid valves from 3.3V GPIO (relevant if expanding to Option B).

---

### 1.6 Valve Driver Options — ESP32 (3.3V GPIO) to 8× 12V/500mA Solenoid Valves

System parameters: ESP32 dev board (3.3V GPIO, ~12mA source max per pin), 8× 12V DC solenoid valves at 500mA each, all 8 potentially open simultaneously (4A total at 12V), inductive loads requiring flyback protection.

---

#### Option 1 — ULN2803A Darlington Array IC

**What it is:** 18-pin DIP IC containing 8 NPN Darlington transistor pairs, one per channel. Texas Instruments, STMicroelectronics, ON Semi all make compatible parts; ~$0.50–$1.00 each.

| Parameter | Value |
|---|---|
| Channels | 8 |
| Output voltage max | 50V |
| Output current max | 500mA continuous per channel (600mA peak) |
| Input series resistor (internal) | 2.7kΩ on each input |
| Input threshold to turn on | V_I(on) = 2.4V max (for 200mA output) |
| Logic family (designed for) | TTL and 5V CMOS |
| Built-in flyback diodes | Yes — one per channel; COM pin must be tied to the 12V load supply rail |
| Package | 18-DIP (through-hole); also SOIC |

**3.3V logic compatibility:** The ULN2803A will turn on with a 3.3V input. The V_I(on) threshold is 2.4V maximum, so a 3.3V ESP32 GPIO (which drives ~2.8V–3.3V high) is above threshold. Confirmed in practice by TI forum engineers and community use. Performance is somewhat reduced compared to 5V drive — expect slightly higher V_CE(sat), but at 500mA loads this is acceptable.

**Critical derating — all 8 channels simultaneous at 500mA:**
The absolute maximum substrate/GND pin current is 2.5A. With 8 channels each at 500mA = 4A, this **exceeds the GND pin limit by 60%** and would destroy the IC. The total package thermal dissipation is also ~2.25W, which at 8 × 500mA is far exceeded. This is the fundamental limitation for this application.

**Workaround:** Use **two ULN2803A ICs** (4 channels each), keeping each IC's total current at 2A. With all 8 valves open: IC1 handles valves 1–4, IC2 handles valves 5–8. Each IC carries 2A peak, within its 2.5A GND pin limit with margin. Total cost: ~$1–2 for both ICs.

**Flyback diodes:** Built-in, no external diodes needed. Connect the COM pin of each IC to the 12V solenoid supply. This is the most convenient aspect of this IC.

**Wiring:**
```
ESP32 GPIO → ULN2803A input pin (IN1–IN8)
ULN2803A output pin (OUT1–OUT8) → solenoid coil (–)
Solenoid coil (+) → 12V supply
ULN2803A COM pin → 12V supply  (activates built-in flyback diodes)
ESP32 GND and 12V supply GND → common GND
```

**Breakout boards:** The ULN2803A is available as a bare DIP IC only — no common breakout boards exist. It's designed to be wired directly on a PCB or perfboard.

**Pros:**
- Extremely simple — 8 channels in one IC (or split across two)
- Built-in flyback diodes, no external parts needed per channel
- Very low cost (~$0.50–$1.00 per IC)
- Well-documented, decades of use
- Works with 3.3V ESP32 GPIO

**Cons:**
- Cannot run all 8 channels at full 500mA from a single IC — requires 2 ICs for this application
- Darlington topology adds ~1–1.4V V_CE(sat) drop at the output (minor, dissipates ~0.5–0.7W per channel; acceptable)
- No optoisolation — ESP32 GND shares with load circuit
- Bare IC only; requires perfboard or PCB, no plug-in module

**Verdict:** Best choice for a custom PCB or neat perfboard build. Two ICs covering 4 channels each is the correct configuration for this application. Lowest cost and parts count of all DIY options.

---

#### Option 2 — ULN2003A Darlington Array IC

**What it is:** Functionally nearly identical to the ULN2803A but with 7 channels instead of 8 and a different internal input resistor suited to higher-voltage logic families.

| Parameter | ULN2003A | ULN2803A |
|---|---|---|
| Channels | 7 | 8 |
| Output voltage max | 50V | 50V |
| Output current max | 500mA per channel | 500mA per channel |
| Input series resistor | 2.7kΩ | 2.7kΩ |
| Logic family targeted | TTL / 5V CMOS | TTL / 5V CMOS |
| Built-in flyback diodes | Yes | Yes |
| Package | 16-DIP | 18-DIP |

**3.3V logic compatibility:** Essentially the same as ULN2803A — V_I(on) is 2.4V max, so 3.3V GPIO will drive it. No practical difference from ULN2803A on this point.

**Thermal/current derating:** Identical to ULN2803A — same GND pin 2.5A max, same package dissipation constraints apply.

**Key difference:** Only 7 channels. For 8 valves, you need two ULN2003A ICs regardless (one handling 4, one handling 4 — wasting 3 channels on the second IC). This makes the ULN2803A strictly better for this application: 8 channels per IC means two ICs cover exactly 8 channels with zero waste.

**Note on input resistor:** Some sources cite the ULN2003A as being optimized for TTL (5V) logic while ULN2803A is rated for "all logic families including CMOS." In practice both ICs behave the same with 3.3V inputs. The real-world difference is negligible here.

**Verdict:** Do not choose ULN2003A over ULN2803A for this application. The channel count mismatch makes it slightly more wasteful with no compensating benefit.

---

#### Option 3 — Pre-made 8-Channel Relay Modules (Optocoupler-Isolated)

**What it is:** A PCB containing 8 electromechanical relays with optocoupler input isolation, IN1–IN8 signal pins, Vcc/GND power, and screw terminal or header outputs (COM/NO/NC per relay). Widely available on Amazon and AliExpress from multiple brands (SainSmart, FlyNoval, generic Chinese OEM).

**3.3V trigger compatibility — the critical split:**

Most inexpensive 8-channel relay modules sold as "Arduino relay modules" are designed for 5V trigger logic. The optocoupler LED on the input side requires ~5–10mA to activate, and the input circuit resistor is sized for 5V. At 3.3V, the LED current may fall below the turn-on threshold and the relay will not reliably activate. This is the most common ESP32 gotcha with relay modules.

Two variants exist:

| Variant | Trigger voltage | Works with ESP32 3.3V? |
|---|---|---|
| Standard "Arduino" 5V relay module | 5V | No — unreliable or fails entirely |
| Modules explicitly marked "3.3V compatible" or "3V optocoupler" | 3.3V | Yes — designed for this |

**Identifying 3.3V-compatible modules:** Look for product listings that state "3.3V relay," "3V optocoupler," or "ESP8266/ESP32 compatible." Example: FlyNoval 8 Channel 3.3V Relay Module (Amazon, ~$10–12) uses 3V optocouplers and is explicitly rated for 3.3V trigger input. Avoid any module that only lists "5V trigger" or says "for Arduino Uno."

**Active-high vs active-low:** Many relay modules are active-low — the relay turns ON when GPIO is pulled LOW (0V), and turns OFF when GPIO is HIGH. This is counter-intuitive and must be accounted for in firmware. Some modules offer a jumper to select polarity. Verify your specific module before writing code.

**Current and voltage ratings:** Relay contacts on common modules are rated 10A at 250V AC / 10A at 30V DC. Well above the 12V/500mA needed for solenoid valves. The relay coil itself draws ~70–90mA at the coil supply voltage — this is drawn from Vcc (not from the ESP32 GPIO).

**Power supply note:** These modules require a separate coil supply (typically 5V from the module's Vcc pin). The signal input goes through the optocoupler. On dual-supply modules, the optocoupler input side is powered by the ESP32's 3.3V, and the coil side by a 5V source. This eliminates ground loop issues. Confirm the module you select has this dual-supply architecture if you want full isolation.

**Flyback diodes:** Relay coil flyback is typically handled internally on relay modules. However, the relay contact output side provides no flyback protection for the solenoid — the solenoid's own flyback spike is suppressed by the relay contact arc quenching and any external diode you add. Best practice: add a 1N4007 across each solenoid coil (at the valve terminals), independent of the relay module.

**Wiring:**
```
ESP32 GPIO (3.3V) → optocoupler input (IN1–IN8)
Module Vcc → 5V supply (for relay coils)
Module GND → common GND
Relay COM → 12V supply
Relay NO → solenoid coil (+)
Solenoid coil (–) → GND
1N4007 diode across each solenoid coil (external, at valve)
```

**Cost:** ~$8–12 for an 8-channel module. Plus 8× 1N4007 diodes (~$1).

**Pros:**
- Full galvanic isolation between ESP32 and high-side circuit (via optocoupler)
- Very high contact current rating (10A) — no derating concerns
- Works with 12V, 24V, or any voltage the relay contacts can handle
- Plug-in module, minimal soldering
- Widely available, many tutorials

**Cons:**
- Most common modules require 5V logic — must specifically source 3.3V-compatible variant
- Active-low logic is confusing and must be handled in firmware
- Electromechanical relays produce audible clicks during valve switching (minor for plant watering)
- Relay mechanical lifetime: typically 100,000 operations; fine for daily watering but worth noting
- External flyback diodes needed on solenoid side (relay contacts do not suppress load-side inductive spikes; the arc quenches but does not clamp)
- Module typically needs 5V coil supply — requires a 5V rail (from USB adapter or buck converter)

**Verdict:** Good choice if isolation between ESP32 and valve circuit is important, or if you prefer plug-and-play assembly. Must buy a module explicitly rated for 3.3V trigger. Add external flyback diodes at the solenoid terminals.

---

#### Option 4 — Pre-made 8-Channel MOSFET Driver Boards

**What it is:** A PCB containing multiple N-channel MOSFETs wired as low-side switches, one per channel, with (ideally) gate drive resistors and flyback diodes. Far fewer standardized pre-built 8-channel MOSFET modules exist compared to relay modules.

**The 3.3V gate drive problem:**

This is the most critical issue for ESP32 use. Standard power MOSFETs (IRF520, IRF540, IRFZ44N) have gate threshold voltages (V_GS(th)) of 2–4V to just begin conducting, and require 8–10V on the gate to reach full R_DS(on) and maximum current capacity. At 3.3V gate drive, these devices are partially on — they conduct but with much higher on-resistance, generating significant heat. They should not be used with 3.3V logic at 500mA loads.

Logic-level MOSFETs required for 3.3V drive (V_GS(th) 1–2.5V, fully on at 3.3V):

| Part | V_DS max | I_D max | V_GS(th) | R_DS(on) at 3.3V | Notes |
|---|---|---|---|---|---|
| IRLB8721PbF | 30V | 62A | 1.35–2.35V | ~8.7mΩ | TO-220; excellent at 3.3V |
| IRLZ44N | 55V | 47A | 1–2V | ~17.5mΩ at 3.3V | TO-220; well proven |
| AOD4184 / D4184 | 40V | 50A | ~2–4V (uncertain) | moderate | Common on pre-made modules; may not fully switch at 3.3V — some sources report marginal behavior |
| IRLB3034PbF | 40V | 195A | 1–2V | ~1.4mΩ | Overkill but works perfectly |
| STN4NF03L | 30V | 4A | ~1V | very low | SOT-223; good for ≤4A |

**IRF520 warning:** The IRF520 is widely used on cheap "MOSFET driver modules" sold for Arduino. Its V_GS(th) is 2–4V and it is rated for 10V gate drive. At 3.3V it is unreliable. Do not use IRF520-based modules with ESP32 directly.

**Available pre-made modules:**

Single-channel MOSFET modules (IRF520, AOD4184, or generic D4184 boards) are widely sold, ~$1–2 each. Buying 8 gives you 8 independent channels but requires 8 separate modules — messy wiring.

4-channel modules: The YYNMOS-4 (4-channel MOSFET module, uses 60N03 MOSFET, 30V/45A, 5A per channel, includes 1N4148 flyback diodes) is available for ~$5–8. You need two for 8 channels. Rated for 3–20V input; however, at least one source reports that the YYNMOS-4 may not trigger reliably at 3.3V due to optocoupler input resistor values sized for higher voltages — verify with your specific module version before relying on it.

True purpose-built 8-channel logic-level MOSFET boards for 3.3V are not a widely standardized product category. What you will find on AliExpress/Amazon tends to be:
- 8× individual IRF520 modules sold as a set (IRF520 is the wrong MOSFET, as noted)
- Generic D4184/AOD4184 single-channel modules (buy 8, ~$8–12 total)
- 4-channel YYNMOS-4 boards × 2

**Flyback diodes:** This varies heavily by module. Some modules include a small diode (often 1N4148 — fast but low current). The D4184 module documentation explicitly warns that it has **no flyback diode**. Always verify and add 1N4007 diodes externally at the solenoid terminals for certainty.

**Wiring (low-side switch, per channel):**
```
ESP32 GPIO (3.3V) → gate (via 100–470Ω resistor)
MOSFET drain → solenoid coil (–)
Solenoid coil (+) → 12V supply
MOSFET source → GND
1N4007 flyback diode across solenoid coil (cathode to 12V, anode to drain)
```

**Cost:** 8× individual logic-level MOSFET modules: ~$8–16 depending on source and MOSFET used. Or 2× YYNMOS-4: ~$10–16.

**Pros:**
- MOSFETs are solid-state — silent operation, no mechanical wear
- Very low on-resistance (logic-level parts) — minimal heat at 500mA
- Fast switching — not relevant for solenoid valve timing but a nice property
- Lower voltage drop than Darlington arrays
- Can support PWM for variable control if needed in future

**Cons:**
- No standardized high-quality 8-channel 3.3V MOSFET board exists — you assemble from single or 4-channel modules
- Must select logic-level MOSFET parts specifically; easy to accidentally buy the wrong module (IRF520-based)
- Flyback diode inclusion is inconsistent across modules — must verify each product
- More wiring than a single-IC solution
- Pre-made modules often lack optoisolation (ESP32 shares GND with load circuit)

**Verdict:** Good performance, but the pre-made landscape is fragmented. Best option is either (a) build a simple 8-channel board with IRLB8721 or IRLZ44N MOSFETs and 1N4007 diodes directly, or (b) buy 2× YYNMOS-4 boards and verify 3.3V triggering before committing.

---

#### Option 5 — Ready-Made ESP32 + 8-Channel Relay/MOSFET Controller Boards

**What it is:** Integrated boards combining ESP32 and 8-channel relay output on one PCB, ready to program via Arduino IDE or ESPHome.

Two products are relevant:

---

**KinCony KC868-A8 / KC868-A8v3**

- ESP32-WROOM-32 (original) or ESP32-S3 (v3 variant)
- 8× SPDT relays; contact rating 10A at 250V AC (documentation says 10A/220V)
- Relays driven via ULN2003A Darlington array controlled by PCF8574P I2C GPIO expander (not direct ESP32 GPIO)
- 8× optoisolated digital inputs (EL357 optocouplers)
- Also includes RJ45 Ethernet, RS485, I2C headers, analog inputs
- Relay coils driven from internal 12V-to-5V regulation (board requires 12V DC input)
- Logic levels internally: 3.3V ESP32 → I2C expander → ULN2003A → relay coil; no need to worry about 3.3V GPIO limitation
- Price: ~$55–67 depending on configuration (PCB only to PCB + enclosure + accessories)
- ESPHome support confirmed; Tasmota community use documented

Suitability for this application:
- 12V DC contact load well within relay rating
- 500mA per valve well within 10A contact rating
- Board requires 12V DC input supply — already in BOM (Meanwell GST60A12)
- Relay contacts: add external 1N4007 diodes at solenoid terminals for best practice
- Gotcha: relay actuation goes through I2C GPIO expander, which adds firmware complexity vs. direct GPIO; also Ethernet chip occupies 9 GPIOs, limiting direct pin count
- Includes features (Ethernet, RS485, analog inputs) that are unnecessary for this application — you are paying for a more complex board

---

**Waveshare ESP32-S3-ETH-8DI-8RO / 8DI-8RO-C**

- ESP32-S3-WROOM-1U-N16R8 (16MB flash, 8MB PSRAM, dual-core 240MHz)
- 8× SPDT relays; contact rating 10A at 250V AC / 10A at 30V DC
- 8× optoisolated digital inputs (5V–36V input range, NPN or PNP)
- Onboard TVS surge protection
- Power input: 7–36V DC (or 5V USB-C)
- Isolated RS485 interface (standard variant) or isolated CAN bus (C variant)
- Full power supply isolation
- Price: $29.99–$32.99 (RS485 variant) / $44.99–$49.99 (CAN variant) — available on Amazon
- ESPHome support confirmed (devices.esphome.io)

Suitability for this application:
- Relay contact rating (10A at 30V DC) comfortably covers 12V/500mA valves
- 7–36V input means the Meanwell 12V supply powers it directly
- Onboard TVS helps protect against solenoid switching transients
- Full isolation is a quality feature
- Again: add external 1N4007 across each solenoid coil for belt-and-suspenders protection
- Gotcha: relay actuation is controlled through internal logic (PCF8574 or similar expander — confirm in wiki before firmware); not direct GPIO per relay
- RS485/CAN interface, Ethernet, and digital inputs are unnecessary for this project

---

**Summary comparison — ready-made ESP32+relay boards:**

| | KC868-A8v3 | Waveshare ESP32-S3-ETH-8DI-8RO |
|---|---|---|
| ESP32 | ESP32-S3 | ESP32-S3-WROOM |
| Relay channels | 8 | 8 |
| DC contact rating | 10A (verify DC spec) | 10A / 30V DC (confirmed) |
| Relay drive | I2C expander → ULN2003A | Internal (verify) |
| Isolation | Optocoupler inputs | Full power isolation + TVS |
| Power input | 12V DC | 7–36V DC or USB-C |
| Price | $55–67 | $30–50 |
| ESPHome | Yes | Yes |
| Extras | Ethernet, RS485, analog in | Ethernet, RS485 or CAN |

---

### 1.6 Summary and Recommendation

| Option | 3.3V Compatible | Flyback Diodes | Wiring Complexity | Cost (8 ch) | Form Factor |
|---|---|---|---|---|---|
| 2× ULN2803A IC | Yes (verified) | Built-in (via COM pin) | Low — perfboard/PCB | ~$1–2 | Bare ICs |
| ULN2003A (×3) | Yes | Built-in | Low | ~$1.50 | Bare ICs |
| 8-ch relay module (3.3V type) | Yes — if explicitly rated | Partial (add external at solenoid) | Very low | ~$10–12 | Plug-in module |
| 8-ch relay module (5V type) | No | Partial | Very low | ~$8–10 | Plug-in module — DO NOT USE |
| MOSFET modules (logic-level) | Yes — if correct MOSFET | Varies — verify/add external | Medium | ~$8–16 | Multiple modules |
| KC868-A8v3 (integrated) | Yes (internal) | Partial — add external at solenoid | None (all-in-one) | ~$55–67 | Dev board w/ ESP32 |
| Waveshare ESP32-S3-ETH-8DI-8RO | Yes (internal) | TVS onboard + add external at solenoid | None (all-in-one) | ~$30–50 | Dev board w/ ESP32 |

**Recommended path:**

- **Lowest cost / most elegant (custom build):** Two ULN2803A ICs, 4 channels each, COM pins to 12V rail. No external flyback diodes needed for the valve drive circuit. ~$1–2 total. Requires a PCB or tidy perfboard layout. Confirmed 3.3V compatible.

- **Easiest assembly / plug-in (separate ESP32):** A 3.3V-compatible 8-channel relay module (e.g. FlyNoval 8-channel 3.3V with optocouplers, ~$10–12). Add 8× 1N4007 diodes at the solenoid terminals. Handle active-low logic in firmware. Requires a 5V coil supply (USB adapter or buck converter).

- **All-in-one integrated board:** Waveshare ESP32-S3-ETH-8DI-8RO (~$30–50) if you want a single board combining ESP32 + 8-relay output with industrial-grade isolation, ready to run ESPHome. Overkill on features for plant watering, but well-supported and robustly designed. Eliminates separate ESP32 purchase.

**What to avoid:**
- Any relay module listed only as "5V trigger" — will not work reliably with ESP32 3.3V GPIO
- IRF520-based MOSFET modules — not a logic-level device; marginal at 3.3V
- A single ULN2803A driving all 8 channels at full 500mA — exceeds the 2.5A GND pin maximum; must split across two ICs

---

## Phase 2 — Electronics Assembly

### 2.1 Transistor Switch Circuit
- Wire Tiny BLE P4 → 470Ω resistor → ZTX650/651 base
- 10kΩ pull-down from base to GND (installed alongside 470Ω; holds base at 0V when GPIO is inactive)
- Collector → solenoid coil (–), solenoid coil (+) → 12V
- Flyback diode across solenoid (cathode to 12V)
- Common GND between Tiny BLE and 12V supply
- Firmware must set H0H1 high-drive mode on P4 after pinMode() — nRF51822 standard drive (~0.5mA) is insufficient to saturate the transistor at 500mA collector current

### 2.2 Bench Test
- Verify transistor saturates and valve clicks open/closed
- Confirm no voltage spikes on Tiny BLE GPIO (check flyback diode is working)

---

## Phase 3 — Firmware

**Language: Arduino C++.** Target: Seeed Tiny BLE (nRF51822) via sandeepmistry/arduino-nRF5 board package. Entry point is `firmware_ble/watering_system/watering_system.ino`. Compile in Arduino IDE; upload by copying the `.bin` to the MBED drive via `cp` (macOS Finder drag-and-drop is unreliable).

A MicroPython ESP32 implementation exists in `firmware/` — deferred until an ESP32 is acquired.

### 3.1 Core Valve Control

- P4 HIGH → transistor on → valve open; P4 LOW → transistor off → valve closed
- Valve open duration set by `FILL_DURATION_S` (default 2s; calibrate upward)
- Hard safety cap: `VALVE_MAX_ON_S` (default 60s) — valve never stays open longer regardless of config
- Waters immediately on first boot, then every 24 hours

### 3.2 Scheduling

- `millis()`-based interval timing — no RTC, no NTP, no WiFi
- `WATER_INTERVAL_MS = 24UL * 60UL * 60UL * 1000UL` — UL suffixes required to prevent 32-bit overflow before widening
- Unsigned subtraction is rollover-safe: correct for up to ~49 days between checks

### 3.3 Safety and Status

- H0H1 high-drive mode set on valve pin after `pinMode()` — required for nRF51822 to source sufficient base current through 470Ω
- Valve pin written LOW before `pinMode(OUTPUT)` — ensures valve stays closed from first clock cycle
- RGB LED status (active LOW): 3 green blinks on boot, solid green while running, blue during watering cycle

### 3.4 Debug Output
- Serial at 115200 baud — log valve open/close events (visible via serial monitor or `mpremote`)

---

## Phase 4 — Calibration & Testing

### 4.1 Option A — Reservoir Fill & Drip Test
- Run valve and measure time to fill all intermediate reservoirs to capacity
- Confirm manifold distributes water to all reservoirs before any overflow
- Measure time for each reservoir to fully empty; adjust tube diameter/length as needed
- Target: fully empty well before the next scheduled watering cycle

### 4.2 Option B — Duration Calibration
- Run each valve individually; measure volume delivered per second of open time
- Set per-plant durations in firmware to deliver target volumes
- Verify simultaneous operation doesn't starve any line (gravity flow may drop under load)

### 4.3 Full Cycle Test (both options)
- Run several complete cycles on schedule
- Check for leaks, overflow, or under-delivery

---

## Phase 5 — Enclosure & Final Setup

### 5.1 Enclosure
- House electronics in a small project box
- Ensure 12V and Arduino power connections are strain-relieved

### 5.2 Mounting
- Mount gravity reservoir above plants (higher = more head pressure = faster fill)
- Route tubing neatly; secure any intermediate reservoirs (Option A) near each plant

### 5.3 Long-term Validation
- Run for 1–2 weeks unattended
- Check plant health and main reservoir water levels

---

## Future Additions (Out of Scope Now)
- Soil moisture sensors per plant to trigger watering conditionally
- Low-water alert for main reservoir
- Web/app interface for schedule changes (ESP32 + WiFi already in build — interface implementation deferred)

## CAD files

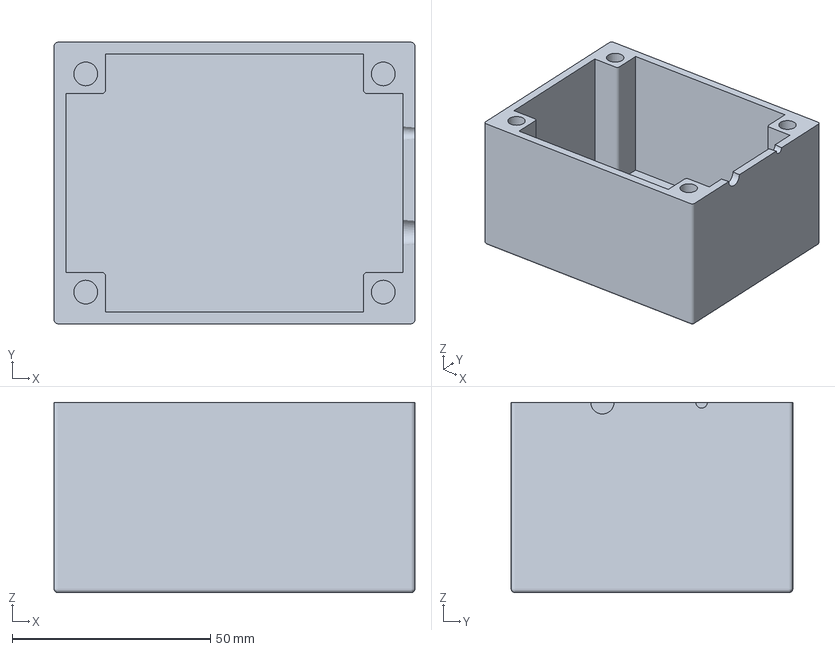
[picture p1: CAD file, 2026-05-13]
print files/electronics enclosure v2 - chamfer fix.3mf
91.0 x 71.0 x 48.0 mm

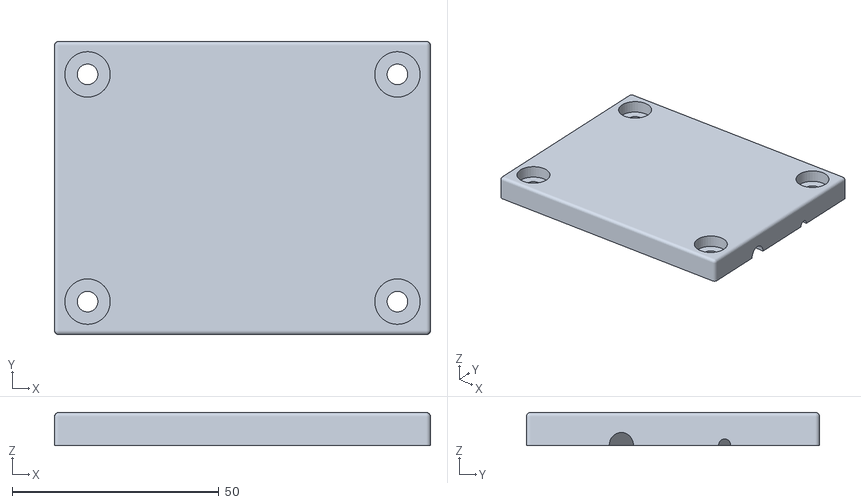
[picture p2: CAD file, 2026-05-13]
print files/enclosure top v3 - hole fix.stl
91.0 x 71.0 x 8.00

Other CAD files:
print files/enclosure body v2 - chamfer fix.stl
print files/enclosure top v3 - hole fix.gcode.3mf
print files/enclosure top v2 - chamfer fix.stl

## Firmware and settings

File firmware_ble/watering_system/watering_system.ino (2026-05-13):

// =============================================================
// Watering System — Seeed Tiny BLE (nRF51822)
// =============================================================
// Single solenoid valve, gravity-fed, 8-plant manifold.
// No WiFi. Valve alternates open/closed on a fixed cycle.
// =============================================================

// ---- Configuration (edit these) -----------------------------

// GPIO pin wired to the TIP121G base via 470 Ω resistor.
#define VALVE_PIN 4

// Valve on-time and off-time, in seconds.
#define VALVE_ON_S  20
#define VALVE_OFF_S 20

// Seeed Tiny BLE RGB LED pin numbers. Active LOW — write LOW
// to turn on, HIGH to turn off.
#define LED_RED   22
#define LED_GREEN 21
#define LED_BLUE  23

// ---- LED helpers --------------------------------------------

void ledOn(int pin)  { digitalWrite(pin, LOW);  }
void ledOff(int pin) { digitalWrite(pin, HIGH); }

void blink(int pin, int n, int onMs = 200, int offMs = 200) {
  for (int i = 0; i < n; i++) {
    ledOn(pin);  delay(onMs);
    ledOff(pin); delay(offMs);
  }
}

// ---- Valve control ------------------------------------------

void openValve()  { digitalWrite(VALVE_PIN, HIGH); }
void closeValve() { digitalWrite(VALVE_PIN, LOW);  }

// ---- Setup --------------------------------------------------

void setup() {
  Serial.begin(115200);
  Serial.println("=== Watering system boot ===");

  // Valve pin: set LOW before enabling output to ensure the
  // valve is closed from the very first clock cycle.
  digitalWrite(VALVE_PIN, LOW);
  pinMode(VALVE_PIN, OUTPUT);

  // The nRF51822 GPIO standard drive is ~0.5 mA — far too low
  // to source enough current through a 470 Ω base resistor.
  // High-drive mode (H0H1) raises the limit to ~5 mA, which
  // is the minimum needed to saturate the TIP121G at 500 mA
  // collector current. This must be set after pinMode().
  NRF_GPIO->PIN_CNF[VALVE_PIN] =
    (NRF_GPIO->PIN_CNF[VALVE_PIN] & ~GPIO_PIN_CNF_DRIVE_Msk)
    | (GPIO_PIN_CNF_DRIVE_H0H1 << GPIO_PIN_CNF_DRIVE_Pos);

  // LED pins: outputs, start HIGH (off, active LOW).
  digitalWrite(LED_RED,   HIGH); pinMode(LED_RED,   OUTPUT);
  digitalWrite(LED_GREEN, HIGH); pinMode(LED_GREEN, OUTPUT);
  digitalWrite(LED_BLUE,  HIGH); pinMode(LED_BLUE,  OUTPUT);

  blink(LED_GREEN, 3);    // 3 blinks: boot complete
  Serial.println("Cycling — valve open/closed every 20s");
}

// ---- Loop ---------------------------------------------------

void loop() {
  openValve();
  ledOn(LED_BLUE);
  Serial.println("Valve open");
  delay((unsigned long)VALVE_ON_S * 1000UL);

  closeValve();
  ledOff(LED_BLUE);
  ledOn(LED_GREEN);
  Serial.println("Valve closed");
  delay((unsigned long)VALVE_OFF_S * 1000UL);
  ledOff(LED_GREEN);
}

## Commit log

2026-03-23 Initial project setup: documentation and plan
    Add CLAUDE.md with hardware/firmware overview and PROJECT_PLAN.md with
    full 5-phase build plan including both single-valve and per-plant valve
    architecture options. Include original sketch photos.
2026-05-06 Project snapshot: Tiny BLE firmware, enclosure design, transistor pull-down
    - Switch MCU from ESP32 to Seeed Tiny BLE (nRF51822); Arduino C++ firmware
    with 24h millis() interval timing, no WiFi/NTP
    - Add 10kΩ base pull-down resistor to transistor driver (BOM + assembly notes);
    documents lesson from blown ZTX650 on first power-up with floating base
    - Add ENCLOSURE_DESIGN.md: 3D-printed body+lid, integrated split cable glands,
    corner extrusion board mounts, IEC C8 power entry, dimensions
    - Add firmware_ble/: Arduino .ino with H0H1 high-drive mode, valve safety cap,
    LED status indicators, rollover-safe millis() scheduling
    - Add firmware/: MicroPython ESP32 implementation (deferred)
    - A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
    [watering_system.ino]
2026-05-06 Remove PROJECT_SNAPSHOT.md — superseded by README.md
2026-05-06 Update plan and log to reflect current build state
    PROJECT_PLAN.md:
    - Swap ESP32 → Seeed Tiny BLE throughout BOM, electrical interfaces, and firmware phases
    - Add 10kΩ pull-down and IEC C8 socket to electronics BOM
    - Update electrical interfaces table with Tiny BLE USB injection power path
    - Rewrite Phase 3 firmware section for Arduino C++ / nRF51822
    - Update Phase 2 assembly notes (H0H1 drive mode, remove RTC step)
    - Update Section 1.5 placeholder BOM to reflect current parts
    PROCESS_LOG.md:
    - Remove order number (identifying information)
    - Add 2026-05-06 entries: MCU switch rationale, firmware decisions,
    transistor failure incident + pull-down fix, enclosure design summary
    Co-Author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
2026-05-06 Add labeled sketches
    sketch_plumbing_overview.jpeg — hand sketch of full plumbing layout:
    reservoir → solenoid valve → 8-port manifold → 8 intermediate
    reservoirs → plants
    sketch_transistor_driver_calc.jpeg — hand working for ZTX650/651
    base resistor: Ic=500mA, β=100, Ib=5mA, R=470Ω derivation
2026-05-13 Firmware running; docs updated; repo cleaned up
    Firmware:
    - Switch to 20s open/closed alternating cycle for valve calibration
    - Correct LED pin assignment (GREEN=21, RED=22, confirmed on hardware)
    - Replace ZTX650 reference with TIP121G throughout
    Docs:
    - Add cost breakdown (~$226 total) to README BOM and PROCESS_LOG
    - Update CLAUDE.md project overview (Tiny BLE, not ESP32; no WiFi)
    - Record firmware confirmed working, power path status, LED pin fix
    Removed:
    - ESP32/MicroPython firmware (firmware/, FIRMWARE_PLAN.md, upload.sh) — path abandoned
    - manifold_options.md — decision resolved, findings captured in PROCESS_LOG
    - Sketch JPEGs — contained GPS coordinates
    - Build artifacts (firm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
    [electronics enclosure v2 - chamfer fix.3mf, enclosure body v2 - chamfer fix.stl, enclosure top v2 - chamfer fix.stl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]
